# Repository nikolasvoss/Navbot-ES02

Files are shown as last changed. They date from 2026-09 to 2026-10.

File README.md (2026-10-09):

# Navbot-ES02 - Open Source Desktop Dual-Wheel Legged Robot

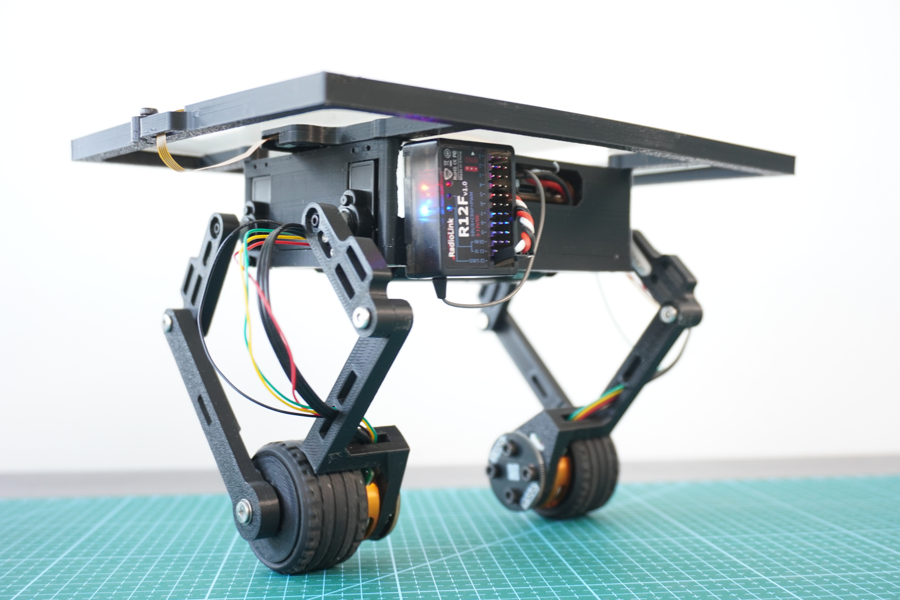
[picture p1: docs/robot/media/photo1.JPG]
robot


**Navbot-ES02** is a compact, open-source desktop robot that combines self-balancing wheels with articulated legs. It’s an experimental platform for exploring locomotion, balance, and user interaction — ideal for makers, educators, and robotics enthusiasts.

Full tutorial: [Frank Fu’s Build Guide](https://frankfu.blog/embodied-ai-robot/diy-desktop-dual-wheel-legged-roboy/)

---

##  Key Features

-  **Self-balancing** using MPU6050 and PID control
-  **Legged motion** using 270° digital servos
-  **Touchscreen interface** for motion control to achieve  ball-balancing
-  **Radiolink T12D RC System** for real-time operation switching via PWM/SBUS.
-  **Modular Arduino-based firmware** for easy customization

---

## Hardware Overview

| Component | Description |
|---|---|
| **MCU** | ESP32-S3 DevKit |
| **Motors** |  2208 90KV 3mm Shaft Gimbal Brushless Motors |
| **IMU** |  ICM42688 a 3-axis gyroscope and a 3-axis accelerometer |
| **Servos** | Pro-Tronik PTK 7452 MG-D 2.8kg/0.11s 12.3g Micro Digital Servo |
| **HMI** | 2.8" resistive/capacitive touchscreen |
| **Battery** | 2Pcs 18650 Battery Charger Pack |
| **Controller** | Radiolink T12D 12CH 2.4G RC Transmitter R12F Receiver |

---

## 📦 Software Structure

```
Navbot-ES02/
├── OllieFOCdrive/     # Motor & balance control
├── TouchUI/           # Touchscreen-based user interface
├── WiFiControl/       # Optional WebSocket/HTML control panel
├── partitions.csv     # Flash partition layout
└── lib/               # Required Arduino libraries
```

---

The current firmware supports the two-wheel balancing robot only. Legacy four-wheel gait control and master/slave communication have been removed. UART1 remains available for the touchscreen, and UART2 handles SBUS.

## Project documentation

The canonical hardware and software documentation follows the two target trees:

- [Robot and ESP32 hardware](docs/robot/hardware/system-overview.md), [robot software/control](docs/robot/software/control/control-flow.md), and the [BLE communication protocol](docs/robot/software/interfaces/NavBot-ES02-BLE-communication-protocol-V1.2.pdf).
- [ros2_pc hardware and attached peripherals](docs/ros2_pc/hardware/README.md) and [ros2_pc software/roadmap](docs/ros2_pc/software/README.md). ros2_pc details remain pending until hardware is selected and verified.

## Getting Started

### 1. Install Requirements

- Arduino CLI with the ESP32 board package installed
- Libraries (via Library Manager or GitHub):
  - [SimpleFOC](https://github.com/simplefoc/Arduino-FOC)
  - [SimpleFOcDrivers](https://github.com/simplefoc/Arduino-FOC-drivers)
  - ArduinoJson
  - Queue (`cppQueue.h`)

The repository does not pin the ESP32 core or Arduino library versions. The build uses the versions installed in your Arduino CLI environment.
Used library versions are recorded per build in firmware-build-environment.json.
    
### 2. Build and flash the firmware

```bash
git clone https://github.com/fuwei007/Navbot-ES02.git
cd Navbot-ES02
python3 scripts/build_firmware.py
```

The command builds the NavBot sketch into `build/flash`. Run `python3 scripts/build_firmware.py --help` to choose another sketch, board, output directory, or build properties. To flash a compiled build, use the configured `navbot_flash` MCP tool `flash_firmware` with the absolute build directory from the active worktree. Check the serial MCP `list_ports` before reporting that the board is disconnected, close the serial MCP connection before flashing, and keep balance disabled with motor outputs safe. See the [canonical USB/serial documentation](docs/robot/software/development/usb-serial-flashing.md) for board settings and verified connection details.

### Safe sensor diagnostics

The full, current procedure is in the [sensor diagnostic guide](docs/robot/software/diagnostics/sensor-diagnostic-mode.md), including safe motor outputs, build and flash steps, SerialPlot settings, the 17-column channel map, and reset troubleshooting. The source currently sets `SENSOR_DIAGNOSTIC_MODE=0`, which builds normal motor-control firmware. Set it to `1` and rebuild for sensor diagnostics. Diagnostic mode skips motor and servo initialization and holds the wheel-driver enable pins low. Support the robot mechanically because the legs are not driven. The diagnostic stream currently uses 576000 baud through the CH340 UART at the user's direction. The hardware UART rate at 576000 has not yet been measured, and this setting is not hardware-accepted.

With the normal image, SerialPlot can log one raw SBUS receiver channel while the robot runs. Use `K60` for CH1 through `K75` for CH16. Each row contains firmware uptime in seconds and the selected channel value. Send `K0` to stop logging. The [sensor diagnostic guide](docs/robot/software/diagnostics/sensor-diagnostic-mode.md) has the SerialPlot setup steps.

### Capture a balance shutdown

With `SENSOR_DIAGNOSTIC_MODE` set to `0`, upload the rebuilt sketch and support the robot so it cannot fall. Close every other serial monitor, then run:

```bash
python3 scripts/capture_balance_trace.py --seconds 20 --output balance-trace.log
```

The script waits for startup, sends `K55`, and records a nominal 142.9 Hz `TRACE` stream, one row for every seventh executed control gate (nominally 1 kHz). Switch RC channel 5 from off to on **once** during the capture. The columns are `time_ms,ch5_mode,ch6_mode,voltage_min_raw_v,voltage_filtered_v,roll_deg,pitch_deg,servo1_cmd_deg,servo2_cmd_deg,servo3_cmd_deg,servo4_cmd_deg,servo1_range_deg,servo2_range_deg,servo3_range_deg,servo4_range_deg,motor1_target,motor2_target,sequence,logger_dropped,uart_write_failures`. Each `range` is the highest minus lowest integer servo command since the preceding row, nominally 7 ms. The minimum voltage uses all battery ADC samples since the previous row; it is still a board ADC estimate, not a measurement of the ESP32's 3.3 V rail. The servo values are commanded angles, not measured shaft positions. The saved log also includes any reboot or brownout text that reaches the serial port. The script sends `K0` at the end to stop tracing. If the robot loses power, retain the log even if the script reports a port error.

After uploading firmware built from the current source, add `--trace-mode 56` and choose a new output file to capture the compact `CTRL` stream instead. It records `time_ms,ch5_mode,voltage_min_raw_v,voltage_filtered_v,roll_deg,gyro_z_rad_s,body_turn_command,angle_error_deg,angle_output,yaw_error,yaw_output,motor1_target,motor2_target,max_servo_range_deg,sequence,logger_dropped,uart_write_failures`. The angle and yaw outputs are the two terms combined into the wheel targets; an inactive balance mode reports zero for their error/output columns. Selected trace modes suppress repeated low-voltage and BLE debug text to keep it out of CSV rows. `body_turn_command` and `yaw_error` use the firmware's numerical scale; do not assume they are physical rad/s without checking the RC mapping. Existing firmware images that only implement `K55` must be reflashed for this mode.

For controller decomposition, `--trace-mode 57` records `BAL` rows: `time_ms,ch5_mode,voltage_min_raw_v,roll_deg,angle_error_deg,angle_out_p,angle_out_i,angle_out_d,body_x,motor1_target,motor2_target,max_servo_range_deg,sequence,logger_dropped,uart_write_failures`. Its shorter lines use the same asynchronous sender and 576000 baud stream. Give each run a unique output filename.

For forward/reverse motion and stopping behavior, `--trace-mode 58` records `DRIVE` rows: `time_ms,ch5_mode,voltage_min_raw_v,voltage_filtered_v,ch3_target,effective_speed_target,motor1_velocity_f,motor2_velocity_f,tick_dt_s,speed_error,speed_out_p,speed_out_i,speed_out_d,speed_output,speed_body_x_raw,body_x,body_pitching_f,roll_ok,angle_output,angle_out_p,angle_out_i,angle_out_d,wheel_speed_feedback,motor1_target,motor2_target,top_ball_x,touch_x,body_pitching,max_servo_range_deg,sequence,logger_dropped,uart_write_failures`. Use this only after confirming the trace output with CH5 off; each run should have a new filename. The logger samples nominally at 142.9 Hz without changing controller gains or the control-gate cadence. Nyquist is about 71.4 Hz; signals above that can alias, and the configured 50 Hz IMU low-pass cutoff is based on nominal 1 kHz sampling rather than a measured runtime cadence. No active-balance hardware measurement has established control-cycle timing or UART integrity under transmission load.

The current `DIAGNOSTIC_LIVE_TUNING_DEFAULTS=1` build starts with angle P/I/D=5/200/0.11 and integral limit 0.1, speed P/I/D=0.045/0.005/0 and integral limit 50, yaw P/I/D=4/0/0, and direct wheel-speed feedback `V=0`. Live tuning starts enabled (`U1`), and these gains also apply when the physical CH5 switch passes briefly through mode 1. Keep CH9 and CH10 centered during driving. The startup speed integral is `SI0.005`, matching the live settings the user reported as free of vibration on 2026-10-01. This observation tested the complete gain set, not the speed integral in isolation. The direct wheel-speed feedback contributes only when the driver requests less speed in the current direction or commands a reversal, including after CH3 returns to neutral, and is limited to ±8 motor-target units. `V0` disables it. `V` reads the current value. The speed-loop BodyX term is limited to ±10 mm and its unsaturated value appears as `speed_body_x_raw` in the DRIVE trace. When absolute `roll_ok` exceeds 5°, further acceleration demand is reduced progressively; by 10° the speed-loop acceleration request is zero. These two angles are initial tuning values. Braking requests and the inner balance output remain available. Compare `ch3_target` with `effective_speed_target` to see the reduction. `W` reads the tilt-reduction strength (default 1), and `W0` disables this new reduction immediately for comparison; `W1` restores it. Live tuning remains enabled, but no USB connection is needed to run the robot after flashing. The wheel speed estimate uses the measured control tick. The SBUS CH3 command is multiplied by 2.0; `ch3_target` shows the scaled target. `SP0.04` changes speed P live; `SP` reads it back. `PL0.05` changes the angle integral limit live; `PL` reads it back. `PP`, `PI`, `PD`, and `YP` read the other relevant gains. `U0` restores this build's tuned startup defaults at the next active control step; `U1` keeps live tuning. Live changes are not stored in flash and reset to these startup values after reboot. The CH3 scaling is fixed in this build and cannot be tuned through serial commands.

To log commands and telemetry through one serial connection, run `python3 scripts/capture_balance_trace.py --trace-mode 56 --interactive --seconds 40 --output control-live-yaw10.log`. The script logs every trace row and each sent command (`# CMD ...`), while showing only every tenth trace row in the terminal. With CH5=0, type `PP` and `YP` to verify the startup gains before entering CH5=2. The interactive input accepts only gain, `U0`/`U1`, and trace-selection commands; it cannot send calibration or motor-drive commands.

For a repeatable agent-facing run summary, pass one or more saved logs to `scripts/summarize_balance_trace.py`. It reports valid and malformed rows, capture span, CH5 mode counts/transitions, and a small set of min/max/mean values without making causal claims:

```bash
python3 scripts/summarize_balance_trace.py balance-trace.log
python3 scripts/summarize_balance_trace.py run-1.log run-2.log --output balance-summary.md
```

For repeated K58 drive/stop trials, one command captures a new log at 576000 baud and writes a short `*.md` report after capture. It refuses to overwrite an existing log or report:

```bash
python3 scripts/run_drive_trial.py --interactive --output drive-test-01.log --seconds 40
```

The report checks trace quality, CH5 activation, CH3 movement, start tilt, and the largest opposite wheel-speed reading in the first second after a CH3 release. If there is no usable stop event, the command returns status 2 and keeps both files. It does not switch the robot. With `--interactive`, type a gain command such as `SP0.04`, then `SP` to read it back, before enabling CH5. The capture logs accepted commands as `# CMD ...` and includes firmware replies. Use a new filename for each gain setting and state the observed movement with the report path. Opening a new serial session may restart the board, so set and read back live gains again in each run.

Compare saved trials without opening Serial or recompiling firmware:

```bash
python3 scripts/analyze_drive_trace.py drive-test-01.log drive-test-02.log --require-stop --output drive-comparison.md
```

`--format json` provides the same measurements for other scripts. A trial with neutral CH3 or a strongly tilted start is flagged as unsuitable for a stop comparison; it is not interpreted as a controller improvement or regression.

### 3. Connect the model remote control
ES02 has 3 lines, namely GND, 5V, and sbus.

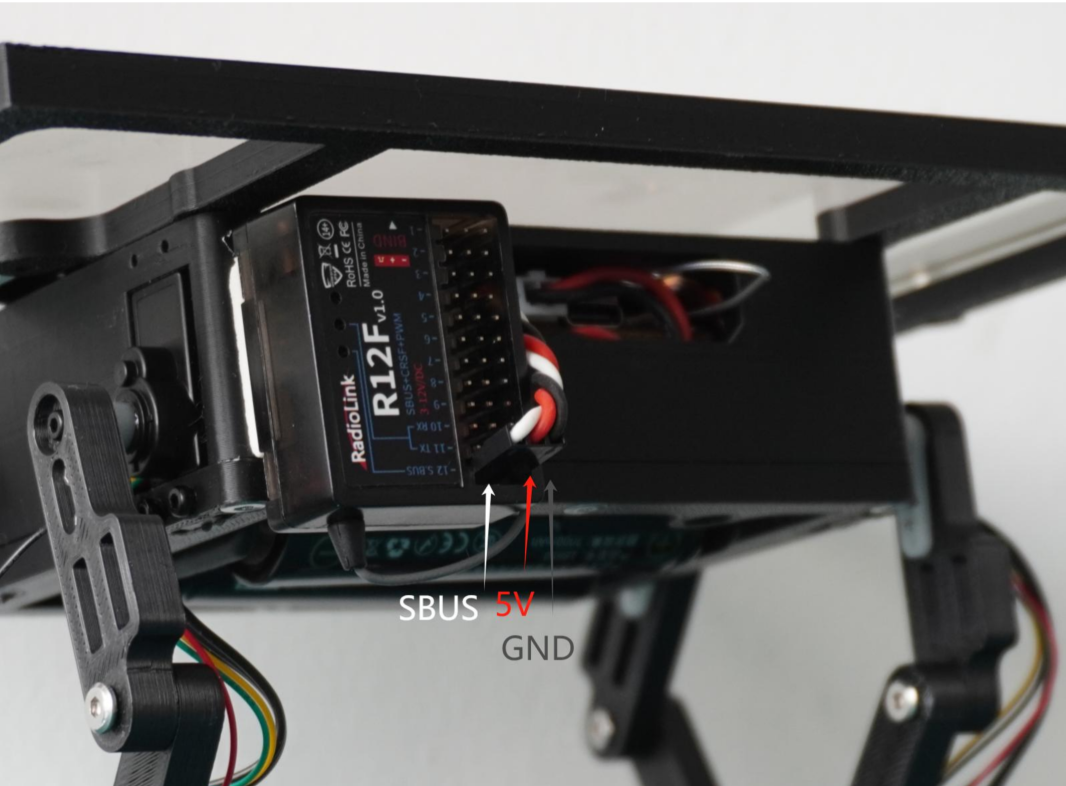
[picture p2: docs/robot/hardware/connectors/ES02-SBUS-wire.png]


The remote control receiver may have multiple interfaces. It is necessary to confirm the sbus
output port by yourself. The following picture shows the wiring ports of the RadioLink receiver.

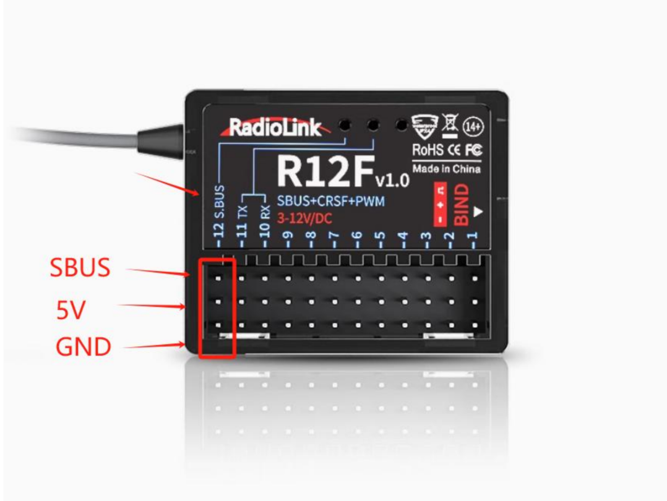
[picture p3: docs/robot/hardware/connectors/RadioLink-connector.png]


The channels of the joystick are generally defaulted to ch1-4. Besides, six auxiliary channels
are needed to switch on some functions. Each remote control is different, and they should be set
according to personal habits. The corresponding functions of ch6-10 can be referred to as follows:

- CH5 : 3-section switch, 0:stop, 1:start, 2:start and touch tablet enable. 
- CH6 : 2-section switch, 0:posture mode, 1:mark mode. 
- CH7 : 2-section switch, manual or auto roll, 0:manual , 1:auto . 
- CH8 : 3-section switch, 0:default, 1:pitching adjust, 2:ball poise. 
- CH9 : The x-coordinate of the small ball . 
- CH10:The y-coordinate of the small ball.

---

## Tourial Videos

- DIY ES02 Desktop dual-wheel legged bot Preview:
  
  Video 2 (https://www.youtube.com/watch?v=u7Jmyq_AXwc)

- Open Source ESP32 DIY Robot ES02: Learn Coding & Robotics | Educational Dual-Wheel Legged Bot:
  Video 1 (https://www.youtube.com/watch?v=hujr_VRSyrw)

---

## Discord link
| Link: [https://discord.gg/syywQ2CKN3](https://discord.gg/syywQ2CKN3)        |
| :------------: |
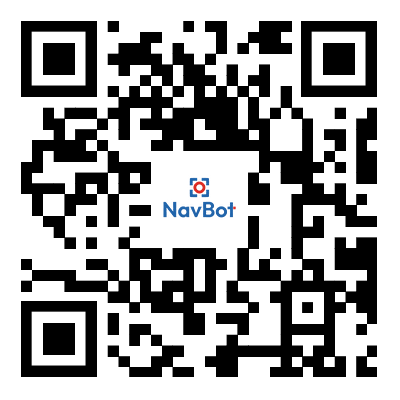
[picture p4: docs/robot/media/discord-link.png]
|  |

---

## Acknowledgments

- [SimpleFOC Community](https://simplefoc.com/)
- [Frank Fu’s Robotics Blog](https://frankfu.blog)
- [LVGL GUI Library](https://lvgl.io/)
- Arduino & ESP32 Open Source Communities

---

> Feel free to fork, contribute, or build your own version!  
> PRs and feedback are always welcome.

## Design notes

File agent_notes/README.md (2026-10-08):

# Agent-only notes

This directory holds agent working context, open investigations, and evidence from the assembled robot. It is not the canonical hardware or software documentation. Put stable, complete documentation under `docs/robot/` or `docs/ros2_pc/`, and keep dated observations with their evidence here.

- [Robot agent notes](robot/README.md)
- [ros2_pc HMMD sensor evidence and references](ros2_pc/sensors/hmmd/README.md)

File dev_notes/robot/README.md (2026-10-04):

# Robot work notes

- Confirm the sender's actual SBUS channel assignments in its monitor. The [RC channel map](../../docs/robot/software/control/rc-channel-map.md) documents the firmware mapping, not the HOTRC switch setup.
- Build with `python3 scripts/build_firmware.py`. For uploads, follow `AGENTS.md` and use the configured `navbot_flash` tool with the active build directory.
- Check the [hardware overview](../../docs/robot/hardware/system-overview.md) before changing wiring. It distinguishes the PCB design from observations on the assembled robot.
- Read the [sensor diagnostic guide](../../docs/robot/software/diagnostics/sensor-diagnostic-mode.md) before collecting sensor-only serial data.

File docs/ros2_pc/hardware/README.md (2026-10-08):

# ros2_pc-Hardware

This directory documents the ros2_pc, its carrier board, power supply, connectors, and attached hardware.

The project has not yet recorded confirmed ros2_pc or carrier-board details here. Do not infer pin assignments, power limits, or peripheral connections from the roadmap. Add each fact with its board revision and evidence when the hardware is selected or inspected.

The [ros2_pc carrier-board pinout](ros2-pc-carrier-board.md) is a reference. It does not confirm that the project has selected or verified that carrier board.

The planned HMMD radar and Roborock LiDAR work is listed in the [ros2_pc software roadmap](../software/roadmap.md). Record their electrical and mechanical details here only after the exact modules are identified.

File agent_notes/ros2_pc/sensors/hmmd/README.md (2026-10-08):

# HMMD-Sensor für Agenten

## Auftrag und aktueller Stand

Der erste [Roadmap-Meilenstein](../../../../docs/ros2_pc/software/roadmap.md) zeigt die HMMD-Range-Doppler-Map stationär in ROS 2 auf dem ros2_pc. ROS 2 ist laut Nutzer bereits auf dem ros2_pc installiert. Die genaue Distribution ist noch nicht erfasst. Sensoranschluss und Live-Daten sind noch nicht geprüft.

## Dokumente finden

- [Lokale Herstellerunterlagen](vendor/README.md) enthält Wiki, Radome-Leitfaden, Beispielpaket und Prüfsummen.
- [HMMD ROS 2 developer guide](../../../../docs/ros2_pc/software/hmmd-ros2.md) ist die zentrale Anleitung zum Bauen und Verwenden der Software.
- [Protokollreferenz](protocol.md) enthält Herstellerangaben und ihre Grenzen.
- [Beobachtungen und offene Punkte](observations.md) enthält den belegten Stand des Aufbaus.
- [Hardwareübersicht](../../../../docs/robot/hardware/system-overview.md) beschreibt die bestehende Navbot-Elektronik. Der stationäre Radaraufbau ist davon getrennt.
- [USB- und Serial-Regeln](../../../../docs/robot/software/development/usb-serial-flashing.md) gelten vor seriellem Zugriff.

## Hinweise für ausführende Agenten

Lies zuerst diesen Einstieg, danach nur die für den Auftrag benötigte Referenz. Unterscheide Herstellerangaben, Nutzerangaben, Vorschläge und gemessene Beobachtungen. Die Quelle des jeweiligen Eintrags entscheidet über seine Aussagekraft.

Verwende für direkte serielle Zugriffe den konfigurierten Serial-MCP. Ermittle den Port mit `list_ports`. Setze nach `open` RTS und DTR niedrig, sofern der Auftrag nichts anderes erfordert. Sende Befehle nur für einen entsprechenden Auftrag. Auf dem ros2_pc muss der Sensor über den verwendeten MCP erreichbar sein.

Prüfe vor Versorgung oder Verkabelung die tatsächliche Modulvariante, Pinbelegung, Spannung und Signalpegel. Übertrage die Pinbelegung eines Raspberry-Pi-Beispiels nicht ungeprüft auf das ros2_pc-Trägerboard.

Notiere neue Hardwarebefunde in `observations.md` mit Datum, Beobachtung, Evidenz und praktischer Konsequenz. Aktualisiere `protocol.md` nur bei belegten Protokollbefunden. Bewahre Rohmitschnitte und Messwerte als Evidenz auf. Dokumentiere Annahmen ausdrücklich.

Nutze Bin-Indizes für die erste Heatmap. Gib keine Meter- oder Geschwindigkeitsachsen ohne nachgewiesene Skalierung an. Die Map liefert keine Links-rechts-Ortung.

Ändere für den stationären Test weder ESP32-Firmware noch Balance-, Motor- oder Fahrsteuerung. LiDAR, SLAM und Navigation gehören zu späteren Aufgaben.

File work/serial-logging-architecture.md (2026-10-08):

# Serial logging merge architecture

## Target behavior retained

The target branch already owns the CH340 `Serial` stream at 576000 baud, a bounded `SerialLogger`, and capture scripts for diagnostic and TRACE/CTRL/BAL/DRIVE rows. Diagnostic mode samples every 10 ms and emits 17 numeric fields. Selected TRACE/CTRL/BAL/DRIVE rows are produced at the existing every-seventh-control-gate boundary. Those formats and rates remain unchanged.

Normal control invokes `print_data()` from the main loop. Selectors 1–45 previously formatted and wrote their values inline. They now copy those already available values into a fixed selected-debug record at the same call boundary. Selector 8 keeps its existing 50 ms throttle. Selectors 55–58 continue through the target's typed row builders and retain the existing CSV suffix fields consumed by capture and summary tools.

## Single queue and sender

The target `SerialLogger` is the only asynchronous logger. Its fixed record union holds either an existing target row or a selected-debug payload. One statically allocated `xQueueCreateStatic()` queue has 32 records; its control block and byte storage are marked `DRAM_ATTR`. On the ESP32, a `SerialLogRecord` is 168 bytes and the queue reserves 5,376 bytes of internal RAM.

The producer snapshots fields into the fixed record and calls `xQueueSend(..., 0)`. It does not format text, allocate memory, write to Serial, or wait for the queue. The logger sender receives a record before formatting it in a 384-byte stack buffer and writing it to Serial, so a blocked UART holds neither the producer nor a queue slot.

On first queue overflow, sender startup failure, or sender write failure, a small sticky status records the reason. Subsequent submissions are rejected and a saturating 8-bit rejected count is retained. The stream has no completion marker or successful-completion state. Queue and sender status do not change motor enables, balance calculations, or fall/safety decisions.

Selected debug output is the only new record kind; it uses the existing SerialLogger sender. The mode gate suppresses other existing BLE/robot debug prints while a selected log mode is active, avoiding another concurrent debug writer. Existing Commander and setup output are not serialized with these records and may still interleave as before.

## Verification

`scripts/test_serial_logger.py` compiles the actual formatter and sender against host FreeRTOS/UART stubs. It blocks the sender inside the UART write, fills the 32-slot queue, times the rejecting producer call, releases the writer, and checks FIFO output, reuse, overflow status, and the target CSV column counts. Normal and diagnostic firmware builds verify the target FreeRTOS integration. Hardware timing and CH340 receive behavior are not measured by these checks.

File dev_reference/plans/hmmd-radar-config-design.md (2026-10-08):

# HMMD radar configuration design

## Caller usage

The radar page shows a small settings area next to or directly below the heatmap. On first connection it reads the confirmed values. Each row has one integer draft and an Apply button:

- **Maximum distance gate**, 0–15 gates. Help: “Limits the farthest distance gate used for detections.”
- **Target disappearance delay**, 0–65535 seconds. Help: “How long a target remains reported after it disappears.”

The page keeps draft values separate from device-confirmed values. A displayed value changes only after the corresponding setting is read back. Save acknowledgment is shown as a separate fact and does not imply persistence across power loss. Bridge timeout/disconnect or device timeout leaves the last confirmed value visible but stale until a fresh read.

```js
const settings = new RadarSettings(client);
await settings.read(); // both confirmed device values
await settings.set("maximumDistanceGate", draft);
await settings.set("targetDisappearanceDelaySeconds", draft);
```

The UI and ROS boundary reject invalid integers and ranges. Only one setting is written per operation, so a stale draft cannot rewrite the other setting.

## Ownership and module map

- `hmmd_interfaces` defines two typed ROS services: one coherent read of both settings and one write of exactly one selected setting.
- `hmmd_radar.protocol` privately encodes verified firmware v1.6.1 commands and decodes command replies; the existing map parser remains specialized for map frames.
- `SerialSession` remains the only UART reader and writer. It exclusively coordinates command replies and map frames during a bounded transaction, retaining complete interleaved maps in a bounded buffer for publication when the service returns.
- `HmmdSensorNode` validates service inputs, maps session outcomes into typed responses, and publishes any map frames collected by the session. Keep the current single-threaded executor; do not add a lock or second reader.
- The production endpoint manifest declares only the two new services. `RosbridgeClient.callService` remains the browser transport.
- `web/radar_settings.mjs` hides ROS selector/outcome details behind `read()` and `set(setting, value)`. `app.mjs`, `index.html`, and `style.css` render two controls near the radar image with draft, confirmed, pending, stale, and error states.
- Extend the existing protocol/session/ROS and browser fixture tests for observable contracts. Update `docs/ros2_pc/software/hmmd-ros2.md` and `agent_notes/ros2_pc/sensors/hmmd/protocol.md` with the service behavior and actual hardware evidence.

## Service contract

`GetRadarConfig.srv` returns both settings only when both device reads are valid, plus explicit outcome/stage and concise detail. `SetRadarSetting.srv` accepts a closed setting selector and one integer value. The driver performs write → positive ACK → same-setting readback → exact match → save → positive save ACK. It returns separate write/save ACK flags, observed value when available, and named outcome/stage. A response is successful only when the readback matches and save is acknowledged. It must not claim power-cycle persistence.

Reject unknown selectors, booleans, non-integers, and out-of-range requests before serial I/O. A write timeout is uncertain; never retry it automatically, and require a fresh read before another write. Keep per-stage and total deadlines finite, with the service/manifest timeout longer than the session transaction. Drop late command replies rather than associating them with a subsequent operation.

## UART/map transaction

The current single-threaded `rclpy.spin()` serializes polling and service callbacks. During the synchronous service callback, `SerialSession` itself drains bounded chunks and classifies both map and command frames; it routes only the matching reply to the active step and retains complete map frames in a bounded buffer for the next publish. This briefly pauses ROS map publication but does not silently discard interleaved map frames. Keep one outstanding device command. Do not retry after I/O loss because the device may have applied the write before disconnection.

The hardware evidence covers firmware `v1.6.1`, maximum gate `12`, and disappearance delay `30 s`: each unchanged value was written, positively acknowledged, read back, and followed by a save acknowledgment. This does not establish power-cycle persistence or authorize changing either value in this task.

## Synthesis decision

Use candidate 1's coherent snapshot read and per-setting write services. Graft candidate 3's domain-oriented browser wrapper so page code does not manipulate ROS selectors or numeric result codes. The read/set transaction stays in one `SerialSession`; candidate 2's paired-value write is rejected because a one-row edit could rewrite a stale value. Candidate 3's generic operation/setting service is rejected because it permits meaningless field combinations and makes stage reporting less precise. The cross-judge found no red-flag blocker and favored this shape for correctness and scope.

The Gemini CLI review did not run successfully: its adapter rejected the supplied task name before reviewing any design. No Gemini findings are attributed to this decision.

## Tradeoffs and open risks

- Keep synchronous bounded transactions and accept a short map publication pause; revisit the ownership model only if measured device latency exceeds the budget.
- Keep explicit browser and ROS validation at their external boundaries and validate all protocol replies before reporting them.
- A timeout after a write is unknown outcome, not proof the setting stayed unchanged. Refresh before another write.
- A save ACK confirms command acceptance only; power-cycle persistence remains untested.
- Preserve maps received during an exchange in a bounded queue; no unbounded buffering.
- Verify the service timeout hierarchy and late-reply drain behavior against the actual serial-session implementation and synthetic streams before enabling the browser control.

## Verification contract

Exercise only no-change hardware writes at gate `12` and delay `30 s`; no deployment or value change. Software checks cover exact boundaries and invalid values, command/reply correlation, ACK/readback/save outcomes and timeouts, interleaved map retention, bounded buffering, no automatic retry, ROS response mapping, manifest-derived endpoints, and browser confirmed-only/reconnect behavior. Existing map/status operation must remain available.

## Implementation reconciliation

The v1.6.1 read replies contain the command ID and uint32 value but do not echo the parameter ID. The serialized session therefore associates a reply only with its one outstanding read step; it drains late command replies between steps and quarantines a timed-out command ID before reusing it. It never retries a setting write. The measured read sequence enters config mode, reads parameter IDs 1 and 4, and sends the acknowledged `0x00FE` exit command. A snapshot succeeds only when both reads and that exit ACK succeed. A setting write stays blocked after an uncertain write or readback mismatch until a successful fresh snapshot.

The mixed stream parser retains the existing map decoder for complete map frames and adds command-frame classification in the same bounded UART stream. Complete maps seen during a service transaction wait in a bounded 64-frame queue for the next poll; queue overflow is counted in HMMD diagnostics. Command stages have finite 350 ms response deadlines and a short bounded late-reply drain, below the 5 s browser service timeout. No second UART reader or executor was introduced.

If later measurements show the finite synchronous transaction exceeds the service budget, stop and return to design/scope review before changing ownership or concurrency.

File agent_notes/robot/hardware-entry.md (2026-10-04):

# Robot hardware entry for agents

Read the [canonical system overview](../../docs/robot/hardware/system-overview.md) first. Open only the needed section of the [electronics reference](../../docs/robot/hardware/electronics/reference.md), then search the [netlist](../../docs/robot/hardware/electronics/netlist.md) for exact designators or nets.

The PCB netlist describes intended connections. Firmware describes configured behavior. The BOM lists proposed parts. Notes under `agent_notes/robot/hardware-findings/` record observations on the assembled robot. Check the physical board when orientation, assembly, or actual wiring remains uncertain.

Before a flash, recheck the board and serial device. See the [USB and serial reminder](usb-serial.md) and the complete [USB and flashing guide](../../docs/robot/software/development/usb-serial-flashing.md).

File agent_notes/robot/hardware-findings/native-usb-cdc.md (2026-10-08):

# Native USB CDC constraint, 2026-10-07

## Observation

Native ESP32-S3 USB CDC is unavailable through the existing USB-C connector without hardware changes. This conclusion combines PCB routing, firmware pin use, and existing device observations. No new physical continuity measurement or wiring trial was performed.

## Evidence

- [PCB netlist](../../../docs/robot/hardware/electronics/netlist.md): `USB1` D+/D− connect to CH340X `U3` UD+/UD−. ESP32 module `U4` GPIO19/20 connect to `RX1`/`TX1` instead.
- [Touch firmware](../../../src/ES-02/OllieFOCdrive/touchscreen.h) uses GPIO20 as UART1 RX and GPIO19 as UART1 TX.
- [Espressif hardware requirements](https://docs.espressif.com/projects/esp-idf/en/stable/esp32s3/api-guides/usb-serial-jtag-console.html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) assign native USB D− to GPIO19 and D+ to GPIO20.
- [Existing board observations](../../../docs/robot/software/development/usb-serial-flashing.md): USB-C enumerated as CH340; enabling USB CDC did not expose a native CDC port and routed sketch output away from the observed UART connection.

## Practical consequence

Use the existing CH340 UART path for logging trials. Native USB requires a separate connection to GPIO19/20 and resolution of the touch-UART conflict, with layout and physical pinout verification before wiring. A firmware option cannot change the USB-C data routing. Neither transport removes the need to keep logging transmission from blocking active balance control.

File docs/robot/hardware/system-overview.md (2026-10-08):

# Roboter mit ESP32: Elektronik-Hardware im Überblick

**Zweck:** Diese Seite in etwa einer Minute lesen. Für Pinbelegung, Strompfade und Quellen nur den benötigten Abschnitt in [hardware reference](electronics/reference.md) öffnen. Für einzelne Bauteile und unbenannte Netze gibt es zusätzlich die durchsuchbare [Bauteil-Netzliste](electronics/netlist.md). Die Angaben beziehen sich auf das eingecheckte EasyEDA-Projekt und die aktuelle Firmware, nicht auf eine Messung jeder Leiterbahn der aufgebauten Platine.

## System auf einen Blick

```text
2 × 18650 in Serie ── Schutz / Schalter ── VIN (2S)
                                         ├─ 2 × MP6536 → 2 × dreiphasiger 2208-Radmotor
                                         ├─ RT8289 → +5 V → XC6210 → +3,3 V
                                         └─ wählbare Servoversorgung (+5 V oder VIN)

ESP32-S3-WROOM-1 (MAIN)
  ├─ 2 getrennte I²C-Busse → je 1 AS5600-Platine (CODER), Radwinkel für SimpleFOC
  ├─ SPI → ICM-42688P, Beschleunigung und Drehrate für Lage/Balanceregelung
  ├─ 6 PWM + 2 Enable → 2 Motor-Endstufen; 4 PWM → Beinservos
  ├─ UART2 → invertierter SBUS-Empfänger; UART1 → Touch-TTL
  ├─ UART0 → CH340X → USB-C für Flash und Serial
  ├─ GPIO17/ADC → 2S-Akkuspannung über 10-kΩ/1-kΩ-Teiler
  └─ BLE → Steuerung ohne zusätzlichen Funkchip
```

Das EasyEDA-Projekt enthält **MAIN** (Steuerung, Versorgung, Motortreiber, Anschlüsse) und **CODER** (AS5600-Encoderplatine; zwei Exemplare laut BOM). Die Mechanik hat zwei bürstenlose Radmotoren und vier Beinservos. Die resistive Touchfläche wird laut BOM über eine separate TTL-Treiberplatine angebunden. RC-Steuerung erfolgt über einen externen Empfänger und dessen SBUS-Ausgang.

## Schnelle Orientierung

| Aufgabe | Relevante Hardware | Direkt weiterlesen |
| --- | --- | --- |
| Radmotor dreht nicht / FOC | MP6536 `U6/U7`, drei Motorphasen je Rad, AS5600 `H5/H6` | [Motoren und Encoder](electronics/reference.md#motoren-und-encoder) |
| Lage, Balance oder Fahrverhalten prüfen | ICM-42688P `U5` an SPI, Akku-ADC `GPIO17` | [Regelungsablauf](../software/control/control-flow.md#noch-nicht-geklärt), [Sensoren](electronics/reference.md#sensoren-und-signale) |
| Servo, Versorgungseinbruch | Vier Servoausgänge `H9/H10`, Versorgungsauswahl `H11`, `VIN` aus 2S-Akku | [Stromversorgung](electronics/reference.md#stromversorgung) und [Anschlüsse](electronics/reference.md#anschlüsse) |
| Fernsteuerung | `H4`: GND, +5 V, SBUS; Inverter `Q1`; ESP32 `GPIO1` | [Anschlüsse](electronics/reference.md#anschlüsse) |
| Touch oder UART | `H2`/`CN4`: UART1; `H3`: UART2; `H1`: UART0 | [Serielle Schnittstellen](electronics/reference.md#serielle-schnittstellen) |
| Einzelner Widerstand, IC-Pin oder unbenanntes Netz | Alle elektrisch verbundenen Pads beider PCBs | [Bauteil-Netzliste](electronics/netlist.md) |
| Flash / USB-Diagnose | USB-C → CH340X → UART0; nicht als natives USB-CDC voraussetzen | [USB/serial guide](../software/development/usb-serial-flashing.md) |

## Wichtige Feststellungen und Konsequenzen

- **Natives USB CDC erfordert eine Hardwareänderung:** Im PCB-Netzplan führt USB-C zu CH340X, nicht zu den nativen USB-Pins des ESP32-S3. GPIO19/20 sind für Touch-UART belegt. Natives USB CDC ist daher über den vorhandenen USB-C-Anschluss ohne Hardwareänderung nicht möglich. Eine Firmwareoption allein genügt nicht. Siehe [serielle Schnittstellen](electronics/reference.md#serielle-schnittstellen).

- **Kein externer RAM:** Laut Nutzerbestätigung vom 28.09.2026 ist ESP32-S3-WROOM-1 bestückt, ohne externen RAM; die Pinbelegung ist korrekt. Die N8R8-Angabe der Netzliste weicht von dieser Hardwareangabe ab. Nur internen SRAM für Logging einplanen; siehe [Hardware constraints for logging](wireless-logging-constraints.md).

- **Servo-Stromschiene:** `H11` verbindet den gemeinsamen Versorgungs-Pin der Servostecker wahlweise mit `+5V` oder `VIN`. Vor Anschluss und Belastung die tatsächlich gesteckte Brücke und die Spannungsverträglichkeit der Servos prüfen. Die Servos hängen nicht am 3,3-V-Regler. Quelle: MAIN-PCB-Netzliste (`H9`, `H10`, `H11`).
- **Akkumessung:** Die Firmware errechnet aus dem GPIO17-ADC einen Akkuwert. Es ist **keine Messung der 3,3-V-Schiene**. Die dokumentierten Messwerte fallen unter Balance-Last stark; Akku, Kontakt, Regler und ADC-Verhalten sind damit noch nicht getrennt beurteilt. Quelle: MAIN-Netzliste `R1/R2`, `ReadVoltage()` und [sensor diagnostic guide](../software/diagnostics/sensor-diagnostic-mode.md).
- **Encoder:** Die gleichen AS5600-I²C-Adressen sind möglich, weil die zwei Radencoder an getrennten ESP32-I²C-Controllern hängen: `GPIO4/5` und `GPIO41/42`. Quelle: MAIN-/CODER-Netzliste und Firmware-Initialisierung.
- **SBUS:** Der Empfänger wird über `H4` mit 5 V versorgt; das Signal läuft über den Transistor `Q1` invertiert zu `GPIO1`/UART2. Den Empfänger-Ausgang und die Pin-Reihenfolge vor dem Stecken prüfen. Quelle: MAIN-Netzliste und [SBUS-Anschlussblatt](connectors/ES02-SBUS-connect.pdf).
- **UART1-Zuordnung:** Die PCB-Netze `RX1`/`TX1` liegen laut ESP32-Symbol an GPIO19/20, die Firmware verwendet für UART1 jedoch RX=GPIO20 und TX=GPIO19. Das ist eine echte Abweichung zwischen Netzbenennung und Softwarebelegung; die Kabelbelegung nicht allein aus den Namen ableiten. Quelle: `U4` in der [Bauteil-Netzliste](electronics/netlist.md) und `touchscreen.h`.
- **5-V-Regler:** `U1`-Pin 5 (`EN`) erscheint im PCB-Export als unverbunden. Daraus allein lässt sich sein Betriebsverhalten nicht bestimmen; bei 5-V-Problemen diesen Pin und das Datenblatt prüfen. Quelle: [Bauteil-Netzliste](electronics/netlist.md).
- **Datenlage:** README, BOM und Schaltplan nennen bei einzelnen Zukaufteilen unterschiedliche Modelle: Die BOM nennt Servo `GX-S7445`, das README `Pro-Tronik PTK 7452 MG-D`. Das README erwähnt außerdem an einer Stelle `MPU6050`, während Schaltplan, BOM und Firmware `ICM-42688P` belegen. Für Pin- und Schaltungsfragen die PCB-Netzliste, für die aktuell ausgeführte Funktion die Firmware heranziehen; konkrete bestückte Kaufteile am Roboter prüfen.

## Quellen und Geltung

- **Schaltplan/Netzliste:** [`hardware/pcb/ProPrj_NavBot-ES02.epro`](../../../hardware/pcb/ProPrj_NavBot-ES02.epro), darin `project.json`, MAIN-/CODER-`.esch` und `.epcb`. Die hier genannten Steckerpins und Netznamen wurden aus `PAD_NET` der jeweiligen `.epcb` gelesen.
- **Zukaufteile:** [`BOM.xlsx`](BOM.xlsx), Tabelle `Sheet1`, Stand des Repositories.
- **Firmware-Zuordnung:** [`src/ES-02/OllieFOCdrive/OllieFOCdrive.ino`](../../../src/ES-02/OllieFOCdrive/OllieFOCdrive.ino), [`ICM42688.h`](../../../src/ES-02/OllieFOCdrive/ICM42688.h), [`touchscreen.h`](../../../src/ES-02/OllieFOCdrive/touchscreen.h), [`FUTABA_SBUS.h`](../../../src/ES-02/OllieFOCdrive/FUTABA_SBUS.h).
- **Beobachtungen am vorhandenen Board:** [USB/serial guide](../software/development/usb-serial-flashing.md) und [sensor diagnostic guide](../software/diagnostics/sensor-diagnostic-mode.md). Diese beschreiben Messungen und lokale Tests; die Netzliste beschreibt das Design.

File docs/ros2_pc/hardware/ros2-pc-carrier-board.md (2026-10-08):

# ros2_pc IO Board pinout

## Scope and status

This page is a manufacturer reference for the ros2_pc IO Board (ros2_pc carrier), the standard carrier shown in the cited Raspberry Pi documents. It does not confirm that the project has selected, bought, inspected, or installed a ros2_pc IO Board. The project’s ros2_pc hardware remains pending.

The current Raspberry Pi IO Board datasheet is document RP-008182, revision 2. Its history records the Rev 2 hardware changes dated 1 August 2025. Raspberry Pi’s design-files page lists the Rev 2 KiCad files, updated 6 October 2025. The product portal identifies the IO Board as SC1751 and SC1967. Check the revision printed on the physical board before using this reference for wiring. See the ros2_pc IO Board datasheet, [ros2_pc IO Board Rev 2 design files](https://pip.raspberrypi.com/categories/1098-design-files), and ros2_pc IO Board product page.

The GPIO alternate functions below come from the ros2_pc datasheet, Table 1. They describe the ros2_pc/RP1 mux, not a promise that every function is enabled in the project’s operating system. The board-specific connector and configuration details come from the ros2_pc IO Board datasheet. Raspberry Pi’s [camera connector pinout](https://www.raspberrypi.com/documentation/accessories/camera.html#pinout-information) and [40-pin HAT+ specification](https://datasheets.raspberrypi.com/hat/hat-plus-specification.pdf) provide connector orientation and standard-header context.

## GPIO header J8

J8 is the standard 40-pin, 2 × 20, 2.54 mm-pitch Raspberry Pi header. Physical pin numbers below follow the standard HAT+ numbering. Use the pin 1 marker on the board and the board drawing when locating pins; do not infer pin 1 from a cable view.

| Physical pins, odd column | Signal | Physical pins, even column | Signal |
| ---: | --- | ---: | --- |
| 1 | 3V3 | 2 | 5V |
| 3 | GPIO2 / I2C1 SDA | 4 | 5V |
| 5 | GPIO3 / I2C1 SCL | 6 | GND |
| 7 | GPIO4 | 8 | GPIO14 / UART0 TX |
| 9 | GND | 10 | GPIO15 / UART0 RX |
| 11 | GPIO17 | 12 | GPIO18 |
| 13 | GPIO27 | 14 | GND |
| 15 | GPIO22 | 16 | GPIO23 |
| 17 | 3V3 | 18 | GPIO24 |
| 19 | GPIO10 / SPI0 SIO0 (MOSI) | 20 | GND |
| 21 | GPIO9 / SPI0 SIO1 (MISO) | 22 | GPIO25 |
| 23 | GPIO11 / SPI0 SCLK | 24 | GPIO8 / SPI0 CE0 |
| 25 | GND | 26 | GPIO7 / SPI0 CE1 |
| 27 | GPIO0 / ID_SD | 28 | GPIO1 / ID_SC |
| 29 | GPIO5 | 30 | GND |
| 31 | GPIO6 | 32 | GPIO12 |
| 33 | GPIO13 | 34 | GND |
| 35 | GPIO19 | 36 | GPIO16 |
| 37 | GPIO26 | 38 | GPIO20 |
| 39 | GND | 40 | GPIO21 |

The bus names in the table are common mappings, not fixed assignments. The complete documented mux options follow. `a0` through `a8` are the alternate-function selector values from Table 1 of the ros2_pc datasheet. A selector omitted from a row has no named function in that table and is reserved.

| GPIO | J8 pin | Alternate functions |
| ---: | ---: | --- |
| 0 | 27 | a0 SPI0_SIO[3]; a1 DPI_PCLK; a2 UART1_TX; a3 I2C0_SDA; a5 SYS_RIO[0]; a6 PROC_RIO[0]; a7 PIO[0]; a8 SPI2_CSn[0] |
| 1 | 28 | a0 SPI0_SIO[2]; a1 DPI_DE; a2 UART1_RX; a3 I2C0_SCL; a5 SYS_RIO[1]; a6 PROC_RIO[1]; a7 PIO[1]; a8 SPI2_SIO[1] |
| 2 | 3 | a0 SPI0_CSn[3]; a1 DPI_VSYNC; a2 UART1_CTS; a3 I2C1_SDA; a4 UART0_IR_RX; a5 SYS_RIO[2]; a6 PROC_RIO[2]; a7 PIO[2]; a8 SPI2_SIO[0] |
| 3 | 5 | a0 SPI0_CSn[2]; a1 DPI_HSYNC; a2 UART1_RTS; a3 I2C1_SCL; a4 UART0_IR_TX; a5 SYS_RIO[3]; a6 PROC_RIO[3]; a7 PIO[3]; a8 SPI2_SCLK |
| 4 | 7 | a0 GPCLK[0]; a1 DPI_D[0]; a2 UART2_TX; a3 I2C2_SDA; a4 UART0_RI; a5 SYS_RIO[4]; a6 PROC_RIO[4]; a7 PIO[4]; a8 SPI3_CSn[0] |
| 5 | 29 | a0 GPCLK[1]; a1 DPI_D[1]; a2 UART2_RX; a3 I2C2_SCL; a4 UART0_DTR; a5 SYS_RIO[5]; a6 PROC_RIO[5]; a7 PIO[5]; a8 SPI3_SIO[1] |
| 6 | 31 | a0 GPCLK[2]; a1 DPI_D[2]; a2 UART2_CTS; a3 I2C3_SDA; a4 UART0_DCD; a5 SYS_RIO[6]; a6 PROC_RIO[6]; a7 PIO[6]; a8 SPI3_SIO[0] |
| 7 | 26 | a0 SPI0_CSn[1]; a1 DPI_D[3]; a2 UART2_RTS; a3 I2C3_SCL; a4 UART0_DSR; a5 SYS_RIO[7]; a6 PROC_RIO[7]; a7 PIO[7]; a8 SPI3_SCLK |
| 8 | 24 | a0 SPI0_CSn[0]; a1 DPI_D[4]; a2 UART3_TX; a3 I2C0_SDA; a5 SYS_RIO[8]; a6 PROC_RIO[8]; a7 PIO[8]; a8 SPI4_CSn[0] |
| 9 | 21 | a0 SPI0_SIO[1]; a1 DPI_D[5]; a2 UART3_RX; a3 I2C0_SCL; a5 SYS_RIO[9]; a6 PROC_RIO[9]; a7 PIO[9]; a8 SPI4_MISO |
| 10 | 19 | a0 SPI0_SIO[0]; a1 DPI_D[6]; a2 UART3_CTS; a3 I2C1_SDA; a5 SYS_RIO[10]; a6 PROC_RIO[10]; a7 PIO[10]; a8 SPI4_MOSI |
| 11 | 23 | a0 SPI0_SCLK; a1 DPI_D[7]; a2 UART3_RTS; a3 I2C1_SCL; a5 SYS_RIO[11]; a6 PROC_RIO[11]; a7 PIO[11]; a8 SPI4_SCLK |
| 12 | 32 | a0 PWM0[0]; a1 DPI_D[8]; a2 UART4_TX; a3 I2C2_SDA; a4 AUDIO_OUT_L; a5 SYS_RIO[12]; a6 PROC_RIO[12]; a7 PIO[12]; a8 SPI5_CSn[0] |
| 13 | 33 | a0 PWM0[1]; a1 DPI_D[9]; a2 UART4_RX; a3 I2C2_SCL; a4 AUDIO_OUT_R; a5 SYS_RIO[13]; a6 PROC_RIO[13]; a7 PIO[13]; a8 SPI5_SIO[1] |
| 14 | 8 | a0 PWM0[2]; a1 DPI_D[10]; a2 UART4_CTS; a3 I2C3_SDA; a4 UART0_TX; a5 SYS_RIO[14]; a6 PROC_RIO[14]; a7 PIO[14]; a8 SPI5_SIO[0] |
| 15 | 10 | a0 PWM0[3]; a1 DPI_D[11]; a2 UART4_RTS; a3 I2C3_SCL; a4 UART0_RX; a5 SYS_RIO[15]; a6 PROC_RIO[15]; a7 PIO[15]; a8 SPI5_SCLK |
| 16 | 36 | a0 SPI1_CSn[2]; a1 DPI_D[12]; a2 UART0_CTS; a5 SYS_RIO[16]; a6 PROC_RIO[16]; a7 PIO[16] |
| 17 | 11 | a0 SPI1_CSn[1]; a1 DPI_D[13]; a2 UART0_RTS; a5 SYS_RIO[17]; a6 PROC_RIO[17]; a7 PIO[17] |
| 18 | 12 | a0 SPI1_CSn[0]; a1 DPI_D[14]; a2 I2S0_SCLK; a3 PWM0[2]; a4 I2S1_SCLK; a5 SYS_RIO[18]; a6 PROC_RIO[18]; a7 PIO[18]; a8 GPCLK[1] |
| 19 | 35 | a0 SPI1_SIO[1]; a1 DPI_D[15]; a2 I2S0_WS; a3 PWM0[3]; a4 I2S1_WS; a5 SYS_RIO[19]; a6 PROC_RIO[19]; a7 PIO[19] |
| 20 | 38 | a0 SPI1_SIO[0]; a1 DPI_D[16]; a2 I2S0_SDI[0]; a3 GPCLK[0]; a4 I2S1_SDI[0]; a5 SYS_RIO[20]; a6 PROC_RIO[20]; a7 PIO[20] |
| 21 | 40 | a0 SPI1_SCLK; a1 DPI_D[17]; a2 I2S0_SDO[0]; a3 GPCLK[1]; a4 I2S1_SDO[0]; a5 SYS_RIO[21]; a6 PROC_RIO[21]; a7 PIO[21] |
| 22 | 15 | a0 SDIO0_CLK; a1 DPI_D[18]; a2 I2S0_SDI[1]; a3 I2C3_SDA; a4 I2S1_SDI[1]; a5 SYS_RIO[22]; a6 PROC_RIO[22]; a7 PIO[22] |
| 23 | 16 | a0 SDIO0_CMD; a1 DPI_D[19]; a2 I2S0_SDO[1]; a3 I2C3_SCL; a4 I2S1_SDO[1]; a5 SYS_RIO[23]; a6 PROC_RIO[23]; a7 PIO[23] |
| 24 | 18 | a0 SDIO0_DAT[0]; a1 DPI_D[20]; a2 I2S0_SDI[2]; a4 I2S1_SDI[2]; a5 SYS_RIO[24]; a6 PROC_RIO[24]; a7 PIO[24]; a8 SPI2_CSn[1] |
| 25 | 22 | a0 SDIO0_DAT[1]; a1 DPI_D[21]; a2 I2S0_SDO[2]; a3 AUDIO_IN_CLK; a4 I2S1_SDO[2]; a5 SYS_RIO[25]; a6 PROC_RIO[25]; a7 PIO[25]; a8 SPI3_CSn[1] |
| 26 | 37 | a0 SDIO0_DAT[2]; a1 DPI_D[22]; a2 I2S0_SDI[3]; a3 AUDIO_IN_DAT0; a4 I2S1_SDI[3]; a5 SYS_RIO[26]; a6 PROC_RIO[26]; a7 PIO[26]; a8 SPI5_CSn[1] |
| 27 | 13 | a0 SDIO0_DAT[3]; a1 DPI_D[23]; a2 I2S0_SDO[3]; a3 AUDIO_IN_DAT1; a4 I2S1_SDO[3]; a5 SYS_RIO[27]; a6 PROC_RIO[27]; a7 PIO[27]; a8 SPI1_CSn[1] |

### Mux rules and common buses

Each GPIO selects one function at a time. Assign a peripheral input to one GPIO only. If the same peripheral input is mapped to multiple GPIOs, the input receives their logical OR. Alternate functions also overlap across peripherals, so a GPIO assigned to one function is unavailable for its other functions.

| Peripheral | GPIO mapping options from the ros2_pc mux table |
| --- | --- |
| I2C0 | GPIO0/1 or GPIO8/9 |
| I2C1 | GPIO2/3 or GPIO10/11 |
| I2C2 | GPIO4/5 or GPIO12/13 |
| I2C3 | GPIO6/7, GPIO14/15, or GPIO22/23 |
| UART1 | TX/RX GPIO0/1; CTS/RTS GPIO2/3 |
| UART2 | TX/RX GPIO4/5; CTS/RTS GPIO6/7 |
| UART3 | TX/RX GPIO8/9; CTS/RTS GPIO10/11 |
| UART4 | TX/RX GPIO12/13; CTS/RTS GPIO14/15 |
| UART0 | TX/RX GPIO14/15; CTS/RTS GPIO16/17; DTR/RI GPIO5/4; DCD/DSR GPIO6/7; IrDA TX/RX GPIO3/2 |

For conventional SPI, SIO0 is MOSI and SIO1 is MISO. SPI0 uses GPIO8–11 for CE0, SIO0, SIO1, and SCLK in the common mapping; CE1 is GPIO7. The complete SPI alternate assignments, including the other controllers, are listed per GPIO above. The ros2_pc datasheet lists SPI0 as a four-chip-select Quad master, SPI1 as a three-chip-select Dual master, SPI2 and SPI3 as two-chip-select Dual masters, SPI4 as a single-chip-select Single slave, and SPI5 as a two-chip-select Dual master.

DPI uses GPIO0–27 for its clock, sync, and up to 24 data signals. SDIO uses GPIO22–27. I2S, PWM, audio, and clock outputs share pins with these and with the bus mappings above. GPIO0 and GPIO1 are the HAT identification signals `ID_SD` and `ID_SC`; they are also associated with MIPI1 I2C. The ros2_pc datasheet says they may be repurposed when that bus is unused, with `force_eeprom_read=0` in `config.txt` to stop the firmware from checking for a HAT EEPROM. The HAT+ specification reserves these pins for HAT identification.

The ros2_pc has additional RP1 GPIO signals that are not on J8. For example, GPIO29 is used for fan tachometer, GPIO34 and GPIO35 for camera control, GPIO38 and GPIO39 for MIPI0 I2C, and GPIO42 for USB VBUS enable. Do not treat these as J8 pins.

## Other connectors used for external devices

| Connector | Interface and pin information |
| --- | --- |
| CAM/DISP0 and CAM/DISP1 | Two 22-pin, 0.5 mm-pitch FFC connectors. Each carries four CSI-2 data lanes, a clock pair, two camera GPIOs, I2C, ground, and 3V3. Use the pin table below. CAM/DISP1 needs both J6 I2C jumpers fitted; it has no camera power-down signal. CAM/DISP0 has camera power-down support. |
| J14 fan | Four-pin, 1 mm-pitch JST-SH PWM fan connector. Pinout is listed below. It uses the 5 V rail. Some fans can run while ros2_pc is shut down because PWM stops. |
| USB-A | Two USB 3.0 host ports. Their VBUS current limit is approximately 1.2 A combined. |
| USB-C data | USB 2.0 data port, primarily for `rpiboot` and board updates. It is separate from the J11 power input. |
| J11 USB-C power | Main 5 V input. A compatible USB-C PD supply negotiates 5 V at 5 A. A standard Raspberry Pi 5 supply is also supported. |
| J8 5 V pins | J8 can also supply the board with external 5 V. The load depends on the ros2_pc and attached peripherals. Do not connect a second supply in parallel with J11 or PoE. |
| HDMI0 and HDMI1 | Two full-size HDMI 2.0 connectors. Their 5 V supply is current limited. |
| Ethernet RJ45 and J9 | Gigabit Ethernet with PoE support. The raw PoE signals route from the RJ45 magnetics to J9 for a PoE HAT. J9 is not a general-purpose power or GPIO connector. Use the revision-matched schematic for any carrier design; this page does not specify a custom PoE harness. |
| M.2 M-key | PCIe Gen 2 ×1 by default, 5 Gb/s, for standard M-key cards such as NVMe SSDs. PCIe Gen 3 ×1 is experimental and unsupported. Check card length, keying, power, and OS driver compatibility. |
| microSD | Available only with ros2_pc Lite modules without eMMC. |
| RTC battery | CR2032 battery socket for the real-time clock. |
| J2 | Boot, EEPROM write-protect, sync, PMIC enable, and wake/shutdown controls. See the pin table below. |
| J3 | Optional and not fitted by default. Three-pin Wi-Fi/Bluetooth disable header. See below. |

### CAM/DISP 22-pin FFC pinout

The signal names and directions below follow Raspberry Pi’s 22-pin camera connector reference. The data and clock pairs are MIPI D-PHY signals, not general-purpose logic pins. Pin 1 is marked by a small dot on ros2_pc IO Boards.

| Pin | Signal | Pin | Signal |
| ---: | --- | ---: | --- |
| 1 | GND | 2 | CAM_DN0 |
| 3 | CAM_DP0 | 4 | GND |
| 5 | CAM_DN1 | 6 | CAM_DP1 |
| 7 | GND | 8 | CAM_CN |
| 9 | CAM_CP | 10 | GND |
| 11 | CAM_DN2 | 12 | CAM_DP2 |
| 13 | GND | 14 | CAM_DN3 |
| 15 | CAM_DP3 | 16 | GND |
| 17 | CAM_IO0 / CAM_GPIO0 | 18 | CAM_IO1 / CAM_GPIO1 |
| 19 | GND | 20 | SCL |
| 21 | SDA | 22 | 3V3 |

The camera I2C lines are pulled up to 3.3 V on the board. The function and direction of `CAM_IO0` and `CAM_IO1` depend on the connected camera or display.

### J14 fan pinout

| Pin | Signal | Standard wire colour |
| ---: | --- | --- |
| 1 | +5V | Red |
| 2 | PWM | Blue |
| 3 | GND | Black |
| 4 | Tach | Yellow |

Raspberry Pi documents the fan header as a 1 mm-pitch JST-SH socket. ros2_pc IO Board Rev 2 adds a pull-up on the fan output for broader fan support. Treat PWM and tach as logic signals, not as power outputs.

### J2 and J3 control headers

| Header pin | Signal | Function |
| ---: | --- | --- |
| J2 1–2 | nRPIBOOT | Jumper forces USB boot instead of on-board eMMC. |
| J2 3–4 | EEPROM_nWP | Jumper write-protects the ros2_pc EEPROM. |
| J2 6 | SYNC_OUT | IEEE 1588 timing signal; may also be configured as an external timing input. |
| J2 12 | PMIC_ENABLE | Power-management control. |
| J2 13–14 | Wake/shutdown button | Connects an external push button for wake or shutdown. |
| J3 1 | WL_nDIS | Connect to J3 pin 2 (GND) to disable Wi-Fi. |
| J3 2 | GND | Ground reference for J3. |
| J3 3 | BT_nDIS | Connect to J3 pin 2 (GND) to disable Bluetooth. |

J6 has two jumpers that route I2C to CAM/DISP1. Fit both when using CAM/DISP1. The ros2_pc IO Board datasheet does not give a separate signal pinout for J6.

## Electrical limits

- The ros2_pc IO Board sets GPIO Vref to 3.3 V by default through R5. Moving R5 to R4 selects 1.8 V. Fit only one of R4 or R5; the change requires soldering.
- The ros2_pc datasheet limits the total load across all 28 GPIO pins to 50 mA. This is an aggregate limit, not a per-pin allowance. GPIO2 and GPIO3 have 1.8 kΩ pull-ups.
- The ros2_pc GPIO voltage must match Vref. Do not connect a 5 V logic output directly to J8. Use a suitable level shifter for signals above the selected Vref.
- The ros2_pc datasheet allows an externally generated 2.5 V GPIO_VREF only under specified power-sequencing and discharge conditions. This is not the ros2_pc IO Board’s R4/R5 selection and is not a stock-board wiring option.
- The two USB-A ports share an approximately 1.2 A VBUS limit. The fan also draws from the 5 V rail. USB and fan loads reduce current available elsewhere.
- J11 is the main power input. The board also permits a 5 V input through J8 and can receive 5 V through its PoE HAT path. Use one designed supply path; do not parallel independent power sources.
- J8 does not expose an ADC input. Use an external ADC for analog sensors.

The ros2_pc datasheet allows 600 mA from each 3.3 V and 1.8 V peripheral rail. That regulator capacity does not raise the separate 50 mA aggregate GPIO limit. The available current also depends on the chosen supply and the other board loads.

## Peripheral and controller details

The ros2_pc datasheet lists five UARTs, four I2C controllers, six SPI controllers, one 4-bit SDIO interface, four PWM channels, two I2S interfaces, two digital PDM audio inputs, two PWM audio outputs, two GPCLK outputs, and a 24-bit DPI interface. Many share J8 pins. The full per-pin table above is the source of truth when selecting a set of functions.

`SPI4` is device/slave mode; SPI0–SPI3 and SPI5 are master mode. Conventional SPI uses SIO0 as MOSI and SIO1 as MISO. The other SIO lanes support wider SPI modes.

The ros2_pc IO Board standard 40-pin header does not include the CM4-style extra 4-pin PoE header. ros2_pc IO Board routes PoE signals to J9 for the optional PoE HAT. Do not reuse a CM4 IO Board PoE header pinout.

## Sources

- ros2_pc IO Board datasheet, RP-008182, revision 2. See sections 2–5 and schematic figures on pages 12–14. The datasheet history lists the Rev 2 hardware changes on 1 August 2025. Product portal entry last checked 4 October 2026.
- ros2_pc datasheet, RP-008180, revision 6. See sections 2.6 and 2.9, Tables 1 and 2, and the GPIO power details.
- [ros2_pc IO Board Rev 2 KiCad design files](https://pip.raspberrypi.com/categories/1098-design-files). The product information portal lists the Rev 2 files as updated 6 October 2025.
- [Raspberry Pi 22-pin camera connector pinout](https://www.raspberrypi.com/documentation/accessories/camera.html#pinout-information).
- [Raspberry Pi HAT+ specification](https://datasheets.raspberrypi.com/hat/hat-plus-specification.pdf).
- [Raspberry Pi computer hardware documentation, Raspberry Pi 5 fan connector pinout](https://www.raspberrypi.com/documentation/computers/raspberry-pi.html#raspberry-pi-5-fan-connector-pinout).

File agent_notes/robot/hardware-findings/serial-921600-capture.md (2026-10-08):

# CH340 capture at 921600 baud produced corrupt rows

Follow-up setting: the user selected 576000 baud for current use after this capture and asked that the physical UART rate be measured in the future. No 576000-baud hardware measurement has been performed; treat it as provisional. A future firmware improvement could let captures select the channels they need to avoid transmitting unused data points. That software change is not part of this hardware observation.

## Observation

On 2026-10-07, the Navbot-ES02 was flashed with the diagnostic image and captured through `/dev/ttyUSB0`, identified as CH340 USB VID:PID `1a86:7523`. Serial MCP used 921600 baud, 8N1, no flow control, and DTR/RTS low. The diagnostic image keeps motor drivers disabled and skips balance and servo setup.

The raw byte capture is available locally at `/tmp/navbot-serial-rate-921600.bin` (900,000 bytes). It spans 95.54 seconds of device `time_us` timestamps, exceeding the requested 60 seconds.

## Evidence

- Valid CSV: 7,824 rows, each with 17 numeric fields; valid receive rate 81.89 rows/s.
- Device sequence span: 9,555 producer records over the timestamp span, or 100.01 records/s inferred from device IDs.
- Malformed numeric lines: 1,714; missing sequence IDs between valid rows: 1,731 across 125 detected gaps.
- Successive valid-row timestamp intervals: minimum/median/p95 10,000 µs; maximum 7,450,000 µs.
- Firmware snapshots reported zero queue drops and zero UART write failures.
- An earlier UTF-8 read attempt failed with an invalid byte sequence. The hex-mode capture contained 900,000 ASCII-range bytes but numerous missing separators and merged lines.

## Practical consequence and limits

Reception at 921600 baud is not reliable on the tested CH340/host/MCP path and is not accepted for data analysis. The zero firmware-side error counters and missing sequence IDs place the observed loss after producer enqueue and UART write accounting, but do not isolate whether the CH340 bridge, physical connection, host driver, or MCP capture decoder is responsible. No lower-baud comparison was run, and no baud fallback was added.

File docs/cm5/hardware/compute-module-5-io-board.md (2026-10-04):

# Raspberry Pi Compute Module 5 IO Board pinout

## Scope and status

This page is a manufacturer reference for the Raspberry Pi Compute Module 5 IO Board (CM5IO), the standard carrier shown in the cited Raspberry Pi documents. It does not confirm that the project has selected, bought, inspected, or installed a CM5IO. The project’s CM5 hardware remains pending.

The current Raspberry Pi IO Board datasheet is document RP-008182, revision 2. Its history records the Rev 2 hardware changes dated 1 August 2025. Raspberry Pi’s design-files page lists the Rev 2 KiCad files, updated 6 October 2025. The product portal identifies the IO Board as SC1751 and SC1967. Check the revision printed on the physical board before using this reference for wiring. See the [CM5IO datasheet](https://pip-assets.raspberrypi.com/categories/1097-raspberry-pi-compute-module-5-io-board/documents/RP-008182-DS-2-cm5io-datasheet.pdf), [CM5IO Rev 2 design files](https://pip.raspberrypi.com/categories/1098-design-files), and [CM5IO product page](https://www.raspberrypi.com/products/compute-module-5-io-board/).

The GPIO alternate functions below come from the [Compute Module 5 datasheet](https://pip-assets.raspberrypi.com/categories/944-raspberry-pi-compute-module-5/documents/RP-008180-DS-6-cm5-datasheet.pdf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), Table 1. They describe the CM5/RP1 mux, not a promise that every function is enabled in the project’s operating system. The board-specific connector and configuration details come from the CM5IO datasheet. Raspberry Pi’s [camera connector pinout](https://www.raspberrypi.com/documentation/accessories/camera.html#pinout-information) and [40-pin HAT+ specification](https://datasheets.raspberrypi.com/hat/hat-plus-specification.pdf) provide connector orientation and standard-header context.

## GPIO header J8

J8 is the standard 40-pin, 2 × 20, 2.54 mm-pitch Raspberry Pi header. Physical pin numbers below follow the standard HAT+ numbering. Use the pin 1 marker on the board and the board drawing when locating pins; do not infer pin 1 from a cable view.

| Physical pins, odd column | Signal | Physical pins, even column | Signal |
| ---: | --- | ---: | --- |
| 1 | 3V3 | 2 | 5V |
| 3 | GPIO2 / I2C1 SDA | 4 | 5V |
| 5 | GPIO3 / I2C1 SCL | 6 | GND |
| 7 | GPIO4 | 8 | GPIO14 / UART0 TX |
| 9 | GND | 10 | GPIO15 / UART0 RX |
| 11 | GPIO17 | 12 | GPIO18 |
| 13 | GPIO27 | 14 | GND |
| 15 | GPIO22 | 16 | GPIO23 |
| 17 | 3V3 | 18 | GPIO24 |
| 19 | GPIO10 / SPI0 SIO0 (MOSI) | 20 | GND |
| 21 | GPIO9 / SPI0 SIO1 (MISO) | 22 | GPIO25 |
| 23 | GPIO11 / SPI0 SCLK | 24 | GPIO8 / SPI0 CE0 |
| 25 | GND | 26 | GPIO7 / SPI0 CE1 |
| 27 | GPIO0 / ID_SD | 28 | GPIO1 / ID_SC |
| 29 | GPIO5 | 30 | GND |
| 31 | GPIO6 | 32 | GPIO12 |
| 33 | GPIO13 | 34 | GND |
| 35 | GPIO19 | 36 | GPIO16 |
| 37 | GPIO26 | 38 | GPIO20 |
| 39 | GND | 40 | GPIO21 |

The bus names in the table are common mappings, not fixed assignments. The complete documented mux options follow. `a0` through `a8` are the alternate-function selector values from Table 1 of the CM5 datasheet. A selector omitted from a row has no named function in that table and is reserved.

| GPIO | J8 pin | Alternate functions |
| ---: | ---: | --- |
| 0 | 27 | a0 SPI0_SIO[3]; a1 DPI_PCLK; a2 UART1_TX; a3 I2C0_SDA; a5 SYS_RIO[0]; a6 PROC_RIO[0]; a7 PIO[0]; a8 SPI2_CSn[0] |
| 1 | 28 | a0 SPI0_SIO[2]; a1 DPI_DE; a2 UART1_RX; a3 I2C0_SCL; a5 SYS_RIO[1]; a6 PROC_RIO[1]; a7 PIO[1]; a8 SPI2_SIO[1] |
| 2 | 3 | a0 SPI0_CSn[3]; a1 DPI_VSYNC; a2 UART1_CTS; a3 I2C1_SDA; a4 UART0_IR_RX; a5 SYS_RIO[2]; a6 PROC_RIO[2]; a7 PIO[2]; a8 SPI2_SIO[0] |
| 3 | 5 | a0 SPI0_CSn[2]; a1 DPI_HSYNC; a2 UART1_RTS; a3 I2C1_SCL; a4 UART0_IR_TX; a5 SYS_RIO[3]; a6 PROC_RIO[3]; a7 PIO[3]; a8 SPI2_SCLK |
| 4 | 7 | a0 GPCLK[0]; a1 DPI_D[0]; a2 UART2_TX; a3 I2C2_SDA; a4 UART0_RI; a5 SYS_RIO[4]; a6 PROC_RIO[4]; a7 PIO[4]; a8 SPI3_CSn[0] |
| 5 | 29 | a0 GPCLK[1]; a1 DPI_D[1]; a2 UART2_RX; a3 I2C2_SCL; a4 UART0_DTR; a5 SYS_RIO[5]; a6 PROC_RIO[5]; a7 PIO[5]; a8 SPI3_SIO[1] |
| 6 | 31 | a0 GPCLK[2]; a1 DPI_D[2]; a2 UART2_CTS; a3 I2C3_SDA; a4 UART0_DCD; a5 SYS_RIO[6]; a6 PROC_RIO[6]; a7 PIO[6]; a8 SPI3_SIO[0] |
| 7 | 26 | a0 SPI0_CSn[1]; a1 DPI_D[3]; a2 UART2_RTS; a3 I2C3_SCL; a4 UART0_DSR; a5 SYS_RIO[7]; a6 PROC_RIO[7]; a7 PIO[7]; a8 SPI3_SCLK |
| 8 | 24 | a0 SPI0_CSn[0]; a1 DPI_D[4]; a2 UART3_TX; a3 I2C0_SDA; a5 SYS_RIO[8]; a6 PROC_RIO[8]; a7 PIO[8]; a8 SPI4_CSn[0] |
| 9 | 21 | a0 SPI0_SIO[1]; a1 DPI_D[5]; a2 UART3_RX; a3 I2C0_SCL; a5 SYS_RIO[9]; a6 PROC_RIO[9]; a7 PIO[9]; a8 SPI4_MISO |
| 10 | 19 | a0 SPI0_SIO[0]; a1 DPI_D[6]; a2 UART3_CTS; a3 I2C1_SDA; a5 SYS_RIO[10]; a6 PROC_RIO[10]; a7 PIO[10]; a8 SPI4_MOSI |
| 11 | 23 | a0 SPI0_SCLK; a1 DPI_D[7]; a2 UART3_RTS; a3 I2C1_SCL; a5 SYS_RIO[11]; a6 PROC_RIO[11]; a7 PIO[11]; a8 SPI4_SCLK |
| 12 | 32 | a0 PWM0[0]; a1 DPI_D[8]; a2 UART4_TX; a3 I2C2_SDA; a4 AUDIO_OUT_L; a5 SYS_RIO[12]; a6 PROC_RIO[12]; a7 PIO[12]; a8 SPI5_CSn[0] |
| 13 | 33 | a0 PWM0[1]; a1 DPI_D[9]; a2 UART4_RX; a3 I2C2_SCL; a4 AUDIO_OUT_R; a5 SYS_RIO[13]; a6 PROC_RIO[13]; a7 PIO[13]; a8 SPI5_SIO[1] |
| 14 | 8 | a0 PWM0[2]; a1 DPI_D[10]; a2 UART4_CTS; a3 I2C3_SDA; a4 UART0_TX; a5 SYS_RIO[14]; a6 PROC_RIO[14]; a7 PIO[14]; a8 SPI5_SIO[0] |
| 15 | 10 | a0 PWM0[3]; a1 DPI_D[11]; a2 UART4_RTS; a3 I2C3_SCL; a4 UART0_RX; a5 SYS_RIO[15]; a6 PROC_RIO[15]; a7 PIO[15]; a8 SPI5_SCLK |
| 16 | 36 | a0 SPI1_CSn[2]; a1 DPI_D[12]; a2 UART0_CTS; a5 SYS_RIO[16]; a6 PROC_RIO[16]; a7 PIO[16] |
| 17 | 11 | a0 SPI1_CSn[1]; a1 DPI_D[13]; a2 UART0_RTS; a5 SYS_RIO[17]; a6 PROC_RIO[17]; a7 PIO[17] |
| 18 | 12 | a0 SPI1_CSn[0]; a1 DPI_D[14]; a2 I2S0_SCLK; a3 PWM0[2]; a4 I2S1_SCLK; a5 SYS_RIO[18]; a6 PROC_RIO[18]; a7 PIO[18]; a8 GPCLK[1] |
| 19 | 35 | a0 SPI1_SIO[1]; a1 DPI_D[15]; a2 I2S0_WS; a3 PWM0[3]; a4 I2S1_WS; a5 SYS_RIO[19]; a6 PROC_RIO[19]; a7 PIO[19] |
| 20 | 38 | a0 SPI1_SIO[0]; a1 DPI_D[16]; a2 I2S0_SDI[0]; a3 GPCLK[0]; a4 I2S1_SDI[0]; a5 SYS_RIO[20]; a6 PROC_RIO[20]; a7 PIO[20] |
| 21 | 40 | a0 SPI1_SCLK; a1 DPI_D[17]; a2 I2S0_SDO[0]; a3 GPCLK[1]; a4 I2S1_SDO[0]; a5 SYS_RIO[21]; a6 PROC_RIO[21]; a7 PIO[21] |
| 22 | 15 | a0 SDIO0_CLK; a1 DPI_D[18]; a2 I2S0_SDI[1]; a3 I2C3_SDA; a4 I2S1_SDI[1]; a5 SYS_RIO[22]; a6 PROC_RIO[22]; a7 PIO[22] |
| 23 | 16 | a0 SDIO0_CMD; a1 DPI_D[19]; a2 I2S0_SDO[1]; a3 I2C3_SCL; a4 I2S1_SDO[1]; a5 SYS_RIO[23]; a6 PROC_RIO[23]; a7 PIO[23] |
| 24 | 18 | a0 SDIO0_DAT[0]; a1 DPI_D[20]; a2 I2S0_SDI[2]; a4 I2S1_SDI[2]; a5 SYS_RIO[24]; a6 PROC_RIO[24]; a7 PIO[24]; a8 SPI2_CSn[1] |
| 25 | 22 | a0 SDIO0_DAT[1]; a1 DPI_D[21]; a2 I2S0_SDO[2]; a3 AUDIO_IN_CLK; a4 I2S1_SDO[2]; a5 SYS_RIO[25]; a6 PROC_RIO[25]; a7 PIO[25]; a8 SPI3_CSn[1] |
| 26 | 37 | a0 SDIO0_DAT[2]; a1 DPI_D[22]; a2 I2S0_SDI[3]; a3 AUDIO_IN_DAT0; a4 I2S1_SDI[3]; a5 SYS_RIO[26]; a6 PROC_RIO[26]; a7 PIO[26]; a8 SPI5_CSn[1] |
| 27 | 13 | a0 SDIO0_DAT[3]; a1 DPI_D[23]; a2 I2S0_SDO[3]; a3 AUDIO_IN_DAT1; a4 I2S1_SDO[3]; a5 SYS_RIO[27]; a6 PROC_RIO[27]; a7 PIO[27]; a8 SPI1_CSn[1] |

### Mux rules and common buses

Each GPIO selects one function at a time. Assign a peripheral input to one GPIO only. If the same peripheral input is mapped to multiple GPIOs, the input receives their logical OR. Alternate functions also overlap across peripherals, so a GPIO assigned to one function is unavailable for its other functions.

| Peripheral | GPIO mapping options from the CM5 mux table |
| --- | --- |
| I2C0 | GPIO0/1 or GPIO8/9 |
| I2C1 | GPIO2/3 or GPIO10/11 |
| I2C2 | GPIO4/5 or GPIO12/13 |
| I2C3 | GPIO6/7, GPIO14/15, or GPIO22/23 |
| UART1 | TX/RX GPIO0/1; CTS/RTS GPIO2/3 |
| UART2 | TX/RX GPIO4/5; CTS/RTS GPIO6/7 |
| UART3 | TX/RX GPIO8/9; CTS/RTS GPIO10/11 |
| UART4 | TX/RX GPIO12/13; CTS/RTS GPIO14/15 |
| UART0 | TX/RX GPIO14/15; CTS/RTS GPIO16/17; DTR/RI GPIO5/4; DCD/DSR GPIO6/7; IrDA TX/RX GPIO3/2 |

For conventional SPI, SIO0 is MOSI and SIO1 is MISO. SPI0 uses GPIO8–11 for CE0, SIO0, SIO1, and SCLK in the common mapping; CE1 is GPIO7. The complete SPI alternate assignments, including the other controllers, are listed per GPIO above. The CM5 datasheet lists SPI0 as a four-chip-select Quad master, SPI1 as a three-chip-select Dual master, SPI2 and SPI3 as two-chip-select Dual masters, SPI4 as a single-chip-select Single slave, and SPI5 as a two-chip-select Dual master.

DPI uses GPIO0–27 for its clock, sync, and up to 24 data signals. SDIO uses GPIO22–27. I2S, PWM, audio, and clock outputs share pins with these and with the bus mappings above. GPIO0 and GPIO1 are the HAT identification signals `ID_SD` and `ID_SC`; they are also associated with MIPI1 I2C. The CM5 datasheet says they may be repurposed when that bus is unused, with `force_eeprom_read=0` in `config.txt` to stop the firmware from checking for a HAT EEPROM. The HAT+ specification reserves these pins for HAT identification.

The CM5 has additional RP1 GPIO signals that are not on J8. For example, GPIO29 is used for fan tachometer, GPIO34 and GPIO35 for camera control, GPIO38 and GPIO39 for MIPI0 I2C, and GPIO42 for USB VBUS enable. Do not treat these as J8 pins.

## Other connectors used for external devices

| Connector | Interface and pin information |
| --- | --- |
| CAM/DISP0 and CAM/DISP1 | Two 22-pin, 0.5 mm-pitch FFC connectors. Each carries four CSI-2 data lanes, a clock pair, two camera GPIOs, I2C, ground, and 3V3. Use the pin table below. CAM/DISP1 needs both J6 I2C jumpers fitted; it has no camera power-down signal. CAM/DISP0 has camera power-down support. |
| J14 fan | Four-pin, 1 mm-pitch JST-SH PWM fan connector. Pinout is listed below. It uses the 5 V rail. Some fans can run while CM5 is shut down because PWM stops. |
| USB-A | Two USB 3.0 host ports. Their VBUS current limit is approximately 1.2 A combined. |
| USB-C data | USB 2.0 data port, primarily for `rpiboot` and board updates. It is separate from the J11 power input. |
| J11 USB-C power | Main 5 V input. A compatible USB-C PD supply negotiates 5 V at 5 A. A standard Raspberry Pi 5 supply is also supported. |
| J8 5 V pins | J8 can also supply the board with external 5 V. The load depends on the CM5 and attached peripherals. Do not connect a second supply in parallel with J11 or PoE. |
| HDMI0 and HDMI1 | Two full-size HDMI 2.0 connectors. Their 5 V supply is current limited. |
| Ethernet RJ45 and J9 | Gigabit Ethernet with PoE support. The raw PoE signals route from the RJ45 magnetics to J9 for a PoE HAT. J9 is not a general-purpose power or GPIO connector. Use the revision-matched schematic for any carrier design; this page does not specify a custom PoE harness. |
| M.2 M-key | PCIe Gen 2 ×1 by default, 5 Gb/s, for standard M-key cards such as NVMe SSDs. PCIe Gen 3 ×1 is experimental and unsupported. Check card length, keying, power, and OS driver compatibility. |
| microSD | Available only with CM5 Lite modules without eMMC. |
| RTC battery | CR2032 battery socket for the real-time clock. |
| J2 | Boot, EEPROM write-protect, sync, PMIC enable, and wake/shutdown controls. See the pin table below. |
| J3 | Optional and not fitted by default. Three-pin Wi-Fi/Bluetooth disable header. See below. |

### CAM/DISP 22-pin FFC pinout

The signal names and directions below follow Raspberry Pi’s 22-pin camera connector reference. The data and clock pairs are MIPI D-PHY signals, not general-purpose logic pins. Pin 1 is marked by a small dot on CM5 IO Boards.

| Pin | Signal | Pin | Signal |
| ---: | --- | ---: | --- |
| 1 | GND | 2 | CAM_DN0 |
| 3 | CAM_DP0 | 4 | GND |
| 5 | CAM_DN1 | 6 | CAM_DP1 |
| 7 | GND | 8 | CAM_CN |
| 9 | CAM_CP | 10 | GND |
| 11 | CAM_DN2 | 12 | CAM_DP2 |
| 13 | GND | 14 | CAM_DN3 |
| 15 | CAM_DP3 | 16 | GND |
| 17 | CAM_IO0 / CAM_GPIO0 | 18 | CAM_IO1 / CAM_GPIO1 |
| 19 | GND | 20 | SCL |
| 21 | SDA | 22 | 3V3 |

The camera I2C lines are pulled up to 3.3 V on the board. The function and direction of `CAM_IO0` and `CAM_IO1` depend on the connected camera or display.

### J14 fan pinout

| Pin | Signal | Standard wire colour |
| ---: | --- | --- |
| 1 | +5V | Red |
| 2 | PWM | Blue |
| 3 | GND | Black |
| 4 | Tach | Yellow |

Raspberry Pi documents the fan header as a 1 mm-pitch JST-SH socket. CM5IO Rev 2 adds a pull-up on the fan output for broader fan support. Treat PWM and tach as logic signals, not as power outputs.

### J2 and J3 control headers

| Header pin | Signal | Function |
| ---: | --- | --- |
| J2 1–2 | nRPIBOOT | Jumper forces USB boot instead of on-board eMMC. |
| J2 3–4 | EEPROM_nWP | Jumper write-protects the CM5 EEPROM. |
| J2 6 | SYNC_OUT | IEEE 1588 timing signal; may also be configured as an external timing input. |
| J2 12 | PMIC_ENABLE | Power-management control. |
| J2 13–14 | Wake/shutdown button | Connects an external push button for wake or shutdown. |
| J3 1 | WL_nDIS | Connect to J3 pin 2 (GND) to disable Wi-Fi. |
| J3 2 | GND | Ground reference for J3. |
| J3 3 | BT_nDIS | Connect to J3 pin 2 (GND) to disable Bluetooth. |

J6 has two jumpers that route I2C to CAM/DISP1. Fit both when using CAM/DISP1. The CM5IO datasheet does not give a separate signal pinout for J6.

## Electrical limits

- The CM5IO sets GPIO Vref to 3.3 V by default through R5. Moving R5 to R4 selects 1.8 V. Fit only one of R4 or R5; the change requires soldering.
- The CM5 datasheet limits the total load across all 28 GPIO pins to 50 mA. This is an aggregate limit, not a per-pin allowance. GPIO2 and GPIO3 have 1.8 kΩ pull-ups.
- The CM5 GPIO voltage must match Vref. Do not connect a 5 V logic output directly to J8. Use a suitable level shifter for signals above the selected Vref.
- The CM5 datasheet allows an externally generated 2.5 V GPIO_VREF only under specified power-sequencing and discharge conditions. This is not the CM5IO’s R4/R5 selection and is not a stock-board wiring option.
- The two USB-A ports share an approximately 1.2 A VBUS limit. The fan also draws from the 5 V rail. USB and fan loads reduce current available elsewhere.
- J11 is the main power input. The board also permits a 5 V input through J8 and can receive 5 V through its PoE HAT path. Use one designed supply path; do not parallel independent power sources.
- J8 does not expose an ADC input. Use an external ADC for analog sensors.

The CM5 datasheet allows 600 mA from each 3.3 V and 1.8 V peripheral rail. That regulator capacity does not raise the separate 50 mA aggregate GPIO limit. The available current also depends on the chosen supply and the other board loads.

## Peripheral and controller details

The CM5 datasheet lists five UARTs, four I2C controllers, six SPI controllers, one 4-bit SDIO interface, four PWM channels, two I2S interfaces, two digital PDM audio inputs, two PWM audio outputs, two GPCLK outputs, and a 24-bit DPI interface. Many share J8 pins. The full per-pin table above is the source of truth when selecting a set of functions.

`SPI4` is device/slave mode; SPI0–SPI3 and SPI5 are master mode. Conventional SPI uses SIO0 as MOSI and SIO1 as MISO. The other SIO lanes support wider SPI modes.

The CM5IO standard 40-pin header does not include the CM4-style extra 4-pin PoE header. CM5IO routes PoE signals to J9 for the optional PoE HAT. Do not reuse a CM4 IO Board PoE header pinout.

## Sources

- [Raspberry Pi Compute Module 5 IO Board datasheet, RP-008182, revision 2](https://pip-assets.raspberrypi.com/categories/1097-raspberry-pi-compute-module-5-io-board/documents/RP-008182-DS-2-cm5io-datasheet.pdf). See sections 2–5 and schematic figures on pages 12–14. The datasheet history lists the Rev 2 hardware changes on 1 August 2025. Product portal entry last checked 4 October 2026.
- [Raspberry Pi Compute Module 5 datasheet, RP-008180, revision 6](https://pip-assets.raspberrypi.com/categories/944-raspberry-pi-compute-module-5/documents/RP-008180-DS-6-cm5-datasheet.pdf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). See sections 2.6 and 2.9, Tables 1 and 2, and the GPIO power details.
- [CM5 IO Board Rev 2 KiCad design files](https://pip.raspberrypi.com/categories/1098-design-files). The product information portal lists the Rev 2 files as updated 6 October 2025.
- [Raspberry Pi 22-pin camera connector pinout](https://www.raspberrypi.com/documentation/accessories/camera.html#pinout-information).
- [Raspberry Pi HAT+ specification](https://datasheets.raspberrypi.com/hat/hat-plus-specification.pdf).
- [Raspberry Pi computer hardware documentation, Raspberry Pi 5 fan connector pinout](https://www.raspberrypi.com/documentation/computers/raspberry-pi.html#raspberry-pi-5-fan-connector-pinout).

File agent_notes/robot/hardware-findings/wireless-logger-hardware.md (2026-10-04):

# Wireless logger hardware finding

The user confirmed on 2026-09-28 that the assembled board uses ESP32-S3-WROOM-1 without external RAM and that its pin assignment is correct. The exported PCB netlist labels U4 as ESP32-S3-WROOM-1-N8R8 while assigning GPIO35–37 to other signals. Treat the user's assembly confirmation as the hardware fact and retain the netlist label as a design discrepancy.

The practical consequence is to budget internal SRAM and leave PSRAM disabled. The free buffer capacity under firmware and Wi-Fi load remains unmeasured. The IMU interrupt pins appear in the U5 symbol but are not connected to U4 in the exported netlist; inspect the physical board before planning interrupt-based FIFO capture.

The full hardware constraints and source distinctions are documented in [docs/robot/hardware/wireless-logging-constraints.md](../../../docs/robot/hardware/wireless-logging-constraints.md).

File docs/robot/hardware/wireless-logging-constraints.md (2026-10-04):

# Hardwarebefunde für kabelloses Logging

Stand 28.09.2026; Dokumentenvergleich und anschließende Hardwarekorrektur durch den Nutzer, keine eigene Messung.

## PSRAM und GPIO35–37

Beobachtung: [PCB-Netzliste](electronics/netlist.md), U4, nennt ESP32-S3-WROOM-1-N8R8 und verbindet zugleich IO35/36 mit LED2/3 sowie IO37 mit EN_B. Die Firmware verwendet diese GPIOs ebenfalls. Laut [Espressif-Datenblatt, Abschnitt 3, Fußnote b](https://documentation.espressif.com/esp32-s3-wroom-1_wroom-1u_datasheet_en.pdf) stehen IO35–37 bei Octal-PSRAM-Modulen nicht für andere Zwecke zur Verfügung.

**Korrektur durch den Nutzer am 28.09.2026:** Bestückt ist ESP32-S3-WROOM-1, es gibt keinen externen RAM, und die Pinbelegung ist korrekt. Dies ist die maßgebliche Angabe zum aufgebauten Roboter. Die N8R8-Bezeichnung der exportierten Netzliste bleibt als abweichende Designangabe erhalten; daraus keinen realen PSRAM-Pinkonflikt ableiten.

Konsequenz: Mit internem SRAM planen, PSRAM deaktiviert lassen und keine Pinänderung vorsehen. Die tatsächlich freie interne Pufferkapazität unter Firmware-/WLAN-Last muss noch gemessen werden. Die Flashgröße ist aus der Basisbezeichnung allein nicht bestimmt.

## IMU-Interrupts

Beobachtung: Die exportierte U5-Belegung enthält INT1/INT2, U4 aber keine entsprechenden Netze; R28 zieht INT2 mit 10 kΩ nach GND. Der vorhandene IMU-Treiber liest Datenregister über SPI und nutzt keinen FIFO-/Interruptpfad.

Konsequenz: Kein vorhandener ESP-Interruptanschluss annehmen. Für FIFO-Erfassung entweder begrenztes Polling entwickeln oder nach Prüfung von Layout und realer Platine einen geeigneten Anschluss planen.

Das [Konzept](../software/proposals/wifi-logging/concept.md) beschreibt Speicherbudget und Entscheidungspunkte.

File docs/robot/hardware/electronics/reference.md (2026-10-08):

# Elektronik-Hardware: technische Referenz

Diese Seite ergänzt die [Systemübersicht](../system-overview.md); alle Bauteil-Pads und Netze stehen in der [Bauteil-Netzliste](netlist.md). **Pins sind physische Steckerkontakte laut EasyEDA-PCB-Netzliste**, GPIOs sind ESP32-S3-Nummern laut Schaltplansymbol und Firmware. Die Kontaktansicht und Kabelrichtung sind damit noch nicht festgelegt; vor dem Einstecken die Platinenbeschriftung prüfen. `MAIN` und `CODER` sind die zwei Boards in `project.json` des [EasyEDA-Projekts](../../../../hardware/pcb/ProPrj_NavBot-ES02.epro).

## Stromversorgung

**Bestückung laut Nutzer, 28.09.2026:** ESP32-S3-WROOM-1 ohne externen RAM; vorhandene Pinbelegung korrekt. Die N8R8-Angabe der Netzliste beschreibt nicht die bestätigte RAM-Ausstattung. Mit internem SRAM planen, PSRAM nicht aktivieren. Quellenabgrenzung und separate IMU-Interruptfrage: [wireless-logging constraints](../wireless-logging-constraints.md).

| Stufe | Bauteile / Netze | Funktion und praktische Folge |
| --- | --- | --- |
| Akku | Externer 2S-18650-Halter → `CN2`: 1 `B2`, 2 `B1`, 3 `B-` | Mittelabgriff `B1`; nicht mit einer einfachen zweipoligen Akkuleitung verwechseln. BOM: ein 2S-Halter und zwei Zellen. |
| Schutz und Ein/Aus | `U8` HY2120-LB, `Q2` WSD3056DN, `SW4`/`SW1`; `SW1` führt `B2` nach `VIN` | Zellschutz und geschaltete Hauptversorgung sind im Design vorhanden. `VIN` versorgt die Motortreiber direkt. Die tatsächliche Abschaltschwelle wurde hier nicht gemessen. |
| Laden / USB | `M1` „2S充电模块“ mit `VBUS`, `B2`, `B1`, `GND`, `VSTA`; USB-C `USB1`; `D5`/`J1` im Pfad zu `+5V` | Laden und USB-Versorgung sind im Design vorgesehen. Kein Ladeverhalten oder gleichzeitiger Betrieb unter Last wurde verifiziert. `VSTA` geht zum ESP32 (`GPIO18`). |
| 5 V | `U1` RT8289GSP, `L1` FXL0630-100-M, Eingangsnetz `VIN`, Ausgang `+5V` | Schaltregler für 5-V-Verbraucher/Anschlüsse. |
| 3,3 V | `U2` XC6210B332MR von `+5V` nach `+3.3V` | Versorgt ESP32, IMU, Encoder und Logik; nicht die Servolast. |
| Servo-Versorgung | `H11`: 1 `+5V`, 2 Servo-Versorgungsnetz, 3 `VIN`; dasselbe Netz an `H9/H10` Pins 3/4 | Dreipolige Auswahl: Brücke 1–2 = 5 V, 2–3 = VIN. Welche Brücke physisch steckt, ist nicht aus dem PCB-Projekt ableitbar. Vor 2S-VIN an Servos deren Zulässigkeit prüfen. |
| Batteriespannung | `R1` 10 kΩ von `VIN` nach `ADC`, `R2` 1 kΩ nach GND, `C1` 100 nF; `ADC` → ESP32 `GPIO17` | Spannungsteiler ca. 1:11. `ReadVoltage()` nutzt eine lokale Kalibrierung `7.77 / 813.43 × ADC`; dieser Schätzwert ist kein direkter 3,3-V- oder Zell-Einzelwert. |

**Prüfpunkt 5-V-Regler:** Im PCB-Netzlistenexport ist Pin 5 (`EN`) des RT8289 `U1` als unverbunden markiert. Die Netzliste allein klärt nicht, ob ein interner Default, eine abweichende reale Bestückung oder ein Designfehler vorliegt. Bei fehlenden 5 V zuerst diesen Punkt am realen Board und mit dem Bauteildatenblatt prüfen; aus der vorhandenen Board-Beobachtung folgt keine Pin-5-Messung.

## Motoren und Encoder

| Kanal | MAIN-Netze / GPIO | Peripherie |
| --- | --- | --- |
| A / `motor1` | `U6` MP6536; `PWM1_A/2_A/3_A` = GPIO15/7/6, `EN_A` = GPIO16; `H7` Pins 1/2/3 = `U_A/V_A/W_A` | Dreiphasiger Radmotor; Firmware `BLDCDriver3PWM(15, 7, 6, 16)`. |
| B / `motor2` | `U7` MP6536; `PWM1_B/2_B/3_B` = GPIO40/39/38, `EN_B` = GPIO37; `H8` Pins 1/2/3 = `U_B/V_B/W_B` | Zweiter dreiphasiger Radmotor; Firmware `BLDCDriver3PWM(40, 39, 38, 37)`. |
| Encoder A | `H5` Pins 1 SDA = GPIO4, 2 SCL = GPIO5, 3 GND, 4 +3,3 V; 5/6 GND laut PCB-Pads | `I2Cone.begin(4, 5, 400000)` und `sensor1` AS5600. Pins 5/6 gehören nicht zum vieradrigen Kabel. |
| Encoder B | `H6` Pins 1 SDA = GPIO41, 2 SCL = GPIO42, 3 GND, 4 +3,3 V; 5/6 GND laut PCB-Pads | `I2Ctwo.begin(41, 42, 400000)` und `sensor2` AS5600. Pins 5/6 gehören nicht zum vieradrigen Kabel. |

Die kleine **CODER**-Platine enthält `U1` AS5600-ASOM, lokale 3,3-V-Abblockung und 10-kΩ-Pull-ups für SDA/SCL. Deren `H1` hat dieselbe logische Reihenfolge: 1 SDA, 2 SCL, 3 GND, 4 3,3 V; weitere Footprint-Pads 5/6 liegen an GND und sind keine zusätzlichen Kabeladern. Der MAIN-Pull-up ist je I²C-Leitung 3,3 kΩ. Die BOM nennt zwei AS5600-Module, zwei 2208-90-kV-Motoren und zwei radiale 6 × 1,5-mm-Magnete. Magnetposition und elektrischer Nullwinkel müssen mechanisch/mit SimpleFOC kalibriert werden; sie folgen nicht aus der Netzliste.

**Polpaare, Recherche vom 01.10.2026:** Die [SimpleFOC-Motordokumentation](https://docs.simplefoc.com/bldc_motors) nennt für den 2208-90KV-Gimbalmotor `12N14P`: 12 Statornuten und 14 Rotorpole, also **7 Polpaare**. Das passt zur Modellangabe `2208-90kv` in `BOM.xlsx`, `Sheet1!D26`. Beide Firmware-Instanzen verwenden bereits fest `BLDCMotor(7)`. Die verbauten Einzelmotoren wurden nicht durch Magnetzählung oder eine unabhängige Messung bestätigt; die BOM beschreibt die vorgesehenen Kaufteile.

Der [Startup-Mitschnitt nach dem Bibliothekswechsel](../../../../build/serial-startup-after-foc-update.txt) zeigt zwei erfolgreiche MCPWM-Initialisierungen und `Motor ready.`, aber Polpaar-Prüfschätzungen von 8,46 und 7,80. In der installierten SimpleFOC-Version 2.3.5 prüft `BLDCMotor::alignSensor()` den Winkelweg gegen den fest konfigurierten Wert und gibt bei Abweichung eine Schätzung aus; es überschreibt `pole_pairs` nicht. **Konsequenz:** 7 beibehalten und die Warnungen als offene Abweichung beim Abgleich behandeln. Aus diesem kurzen Abgleich allein weder 8 Polpaare ableiten noch die Warnung durch Überspringen der Kalibrierung unterdrücken. Eine Last, unvollständige Rotorbewegung oder ein Encoderfehler sind mögliche Ursachen, hier aber nicht nachgewiesen.

## Sensoren und Signale

| Funktion | Chip / Signal | ESP32-S3 und Firmware |
| --- | --- | --- |
| IMU | `U5` ICM-42688P-HXY, SPI `SCLK/MOSI/MISO/CS1` | GPIO3/9/10/13; `ICM42688.cpp` verwendet SPI Mode 3, Beschleunigung ±8 g und Gyro ±2000 °/s bei 1 kHz. `INT1/INT2` sind im Design vorhanden; die gezeigte Firmware liest per SPI. |
| Vier Beinservos | `SERVO1/2/3/4` | GPIO11/12/21/14, 50-Hz-PWM in `ServoControl`; Servo 2/3 sind in der Standard-Ansteuerung invertiert. Die GPIO-Reihenfolge sagt noch nichts über links/rechts an der Mechanik. |
| Betriebs-LEDs | `LED2/LED3` | GPIO35/36; `BOARD_PIN_LED=35` und LOW schaltet die Firmware-LED ein. |
| Ladesignal | `VSTA` | GPIO18; im Schaltplan an `M1`, ohne hier bestätigte Softwareauswertung. |
| Versionskennung | `VERSION_ADC` | GPIO8, Teiler 180 kΩ/100 kΩ; im Design vorhanden, Nutzung der aktuellen Firmware nicht belegt. |

## Anschlüsse

| Stecker | Physische Pins laut PCB | Zweck / Hinweis |
| --- | --- | --- |
| `CN2` | 1 `B2`, 2 `B1`, 3 `B-` | 2S-Akku mit Mittelabgriff. |
| `H4` | 1 GND, 2 +5 V, 3 SBUS-Eingang über `R12/Q1` | Externer RC-Empfänger; siehe [SBUS-Anschlussblatt](../connectors/ES02-SBUS-connect.pdf). |
| `H5`, `H6` | 1 SDA, 2 SCL, 3 GND, 4 +3,3 V | AS5600 A/B; zusätzliche GND-Pads 5/6 erscheinen in der Footprint-Netzliste. |
| `H7`, `H8` | 1 U, 2 V, 3 W | Dreiphasige Motoranschlüsse A/B. |
| `H9` | 1 Servo 1, 2 Servo 2, 3/4 gemeinsame Servo-Versorgung, 5/6 GND | Beinservos 1/2. |
| `H10` | 1 Servo 3, 2 Servo 4, 3/4 gemeinsame Servo-Versorgung, 5/6 GND | Beinservos 3/4. |
| `H11` | 1 +5 V, 2 Servo-Versorgung, 3 VIN | Auswahl der Servo-Versorgung; tatsächliche Brücke vor Betrieb ansehen. |
| `CN3` | 1–4 Servo 1–4, 5–7 GND | Signale/GND, keine Servo-Versorgung auf diesen Pins. |
| `H12` | 1 +5 V, 2 GND, 3 SCLK, 4 MOSI, 5 MISO, 6 CS1, 7 unbelegt, 8 GND | Zusätzlicher SPI-Header; seine +5 V nicht mit 3,3-V-Logikpegeln gleichsetzen. |

## Serielle Schnittstellen

**Natives USB CDC ist über den vorhandenen USB-C-Anschluss ohne Hardwareänderung nicht möglich.** Laut PCB-Netzliste verbinden `D+` und `D−` den Anschluss `USB1` mit CH340X `U3`. Die nativen USB-Pins des ESP32-S3, GPIO20 für D+ und GPIO19 für D−, liegen dagegen auf `TX1` und `RX1` für Touch-UART. Natives USB würde eine separate Verbindung zu diesen Pins und die Auflösung des Touch-UART-Konflikts erfordern. Die Firmwareoption „USB CDC On Boot“ ändert diese Verdrahtung nicht. Quellen: [PCB-Netzliste](netlist.md), [Espressif USB-Anschlussbelegung](https://docs.espressif.com/projects/esp-idf/en/stable/esp32s3/api-guides/usb-serial-jtag-console.html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) und [Beobachtungen am vorhandenen Board](../../software/development/usb-serial-flashing.md).

| Pfad | Steck-/Netzseite | Firmware und Einschränkung |
| --- | --- | --- |
| USB/Debug | USB-C `USB1` → CH340X `U3` → `RX0/TX0`; `H1`: 1 +5 V, 2 GND, 3 RX0, 4 TX0 | Flash/`Serial`; am vorhandenen Board als CH340 `/dev/ttyUSB*` beobachtet. Normalmodus 2 Mbaud, Sensordiagnose 115200 Baud. [USB/serial guide](../../software/development/usb-serial-flashing.md) vor Änderungen lesen. |
| Touch / UART1 | `H2`: 1 +5 V, 2 GND, 3 RX1, 4 TX1; `CN4`: 2 +5 V, 3 GND, 4 RX1, 5 TX1 (1/7 GND) | **PCB-Netznamen:** RX1 an GPIO19, TX1 an GPIO20. **Firmware:** `RXD1=20`, `TXD1=19` – gegenläufig zu den Netznamen. Die Zweirad-Firmware liest die externe Touch-TTL-Platine mit 115200 Baud. Der frühere Vierbein-Master/Slave-Modus wurde am 01.10.2026 entfernt; UART1 bleibt für Touch verfügbar. Vor Verdrahtung physische Leitungsrichtung prüfen. |
| SBUS / UART2 | `H3`: 1 +5 V, 2 GND, 3 RX2, 4 TX2; `H4`: 1 GND, 2 +5 V, 3 SBUS über `Q1` | `RX2/TX2` = GPIO1/2. `FUTABA_SBUS` startet UART2 mit 100000 Baud; der Transistor invertiert den SBUS-Eingang für `RX2`. |

`H1/H2/H3` besitzen laut PCB-Footprint zusätzliche GND-Pads 5/6, aber vier Kabeladern. Bei externen Kabeln die Kontakte 1–4 und die Platinenbeschriftung verwenden. Die BOM nennt drei SH1.0-Kabel mit 200 mm (zwei Encoder, Verbindung zweier Einheiten) und eines mit 100 mm (Touch); für den SBUS-Empfänger ein dreipoliges Kabel.

## Externe Geräte, Modi und Datenqualität

- Die RC-Bedienung ist im [README](../../../../README.md) beschrieben: CH5 Stop/Start/Touch, CH6 Haltung/„Mark“, CH7 Roll manuell/auto, CH8 Standard/Pitch/Ball-Balance, CH9/10 Ballkoordinaten. Diese Zuordnung ist Firmware-/Fernsteuerungs-Konfiguration, keine Eigenschaft des Steckers.
- `SENSOR_DIAGNOSTIC_MODE=1` setzt GPIO16/37 zunächst LOW, überspringt Motor-/Servo-Initialisierung und liefert IMU, Akku-ADC und RC-Zustand als CSV. Für das sichere Diagnoseverfahren und die beobachteten Spannungseinbrüche [sensor diagnostic guide](../../software/diagnostics/sensor-diagnostic-mode.md) lesen.
- Das README enthält ältere oder abweichende Hardware-Angaben (`MPU6050`, anderes Servo-Modell, unklare Touchgröße). Die **PCB-Netzliste** belegt die elektrischen Verbindungen; die **BOM** listet Kaufteile; die **Firmware** belegt gegenwärtig konfigurierte GPIOs und Betriebsarten. Bestückung, Kabelorientierung, Servospannungsbrücke und Spannungen unter Last müssen am realen Board geprüft werden.

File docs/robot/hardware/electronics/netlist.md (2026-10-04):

# Elektronik-Hardware: vollständige logische Bauteil-Netzliste

Diese gezielt durchsuchbare Momentaufnahme ergänzt [Einstieg](../system-overview.md) und [technische Referenz](reference.md). Sie wurde aus den `PAD_NET`-Einträgen der beiden `.epcb` im [EasyEDA-Projekt](../../../../hardware/pcb/ProPrj_NavBot-ES02.epro) abgeleitet. Angegeben sind **Bauteil-Designator, Bauteilwert/Typ, Padnummer und Netz**; wo vorhanden steht der Schaltplansymbol-Pinname in eckigen Klammern. Suche mit `rg "U6|\$1N13944|VIN" docs/robot/hardware/electronics/netlist.md`.

`$1N…` bezeichnet ein unbenanntes, aber elektrisch identisches Netz innerhalb **derselben** Platine. `∅` bezeichnet ein im PCB-Netzlistenexport unverbundenes nummeriertes Pad. Mechanische Board-Geometrie ist ausgelassen; bei mehrfachen Gehäusepads auf einem Netz wird jede eindeutige Padnummer einmal genannt. Die Netzliste beschreibt die **geplante logische Verbindung**, nicht Leiterbahnführung, Schicht, Massefläche, Bauteilplatzierung, Bestückung oder gemessene Funktion. Bei Layout-, SI-/EMV- und Reparaturfragen bleibt der PCB-Editor bzw. die reale Platine maßgeblich.

## MAIN (116 Bauteile)

| Ref | Wert / Typ | Pads → Netze |
| --- | --- | --- |
| `C1` | 100nF | `1=GND, 2=ADC` |
| `C2` | 22uF | `1=GND, 2=VIN` |
| `C3` | 22uF | `1=GND, 2=VIN` |
| `C4` | 100nF | `1=GND, 2=VIN` |
| `C5` | 100nF | `1=$1N2389, 2=$1N2414` |
| `C6` | 22uF | `1=GND, 2=+5V` |
| `C7` | 22uF | `1=GND, 2=+5V` |
| `C8` | 100nF | `1=GND, 2=+5V` |
| `C9` | 10uF | `1=GND, 2=+5V` |
| `C10` | 100nF | `1=GND, 2=+5V` |
| `C11` | 10uF | `1=+3.3V, 2=GND` |
| `C12` | 100nF | `1=+3.3V, 2=GND` |
| `C13` | 1uF | `1=GND, 2=+3.3V` |
| `C14` | 1uF | `1=GND, 2=$1N3674` |
| `C15` | 22uF | `1=+3.3V, 2=GND` |
| `C16` | 100nF | `1=GND, 2=$1N4673` |
| `C17` | 100nF | `1=GND, 2=+3.3V` |
| `C18` | 100nF | `1=$1N10925, 2=U_A` |
| `C19` | 100nF | `1=$1N11051, 2=V_A` |
| `C20` | 100nF | `1=W_A, 2=$1N11092` |
| `C21` | 10uF | `1=$1N11138, 2=GND` |
| `C22` | 10uF | `1=$1N11195, 2=GND` |
| `C23` | 100nF | `1=GND, 2=VIN` |
| `C24` | 100uF | `1=GND, 2=VIN` |
| `C25` | 100nF | `1=$1N14887, 2=U_B` |
| `C26` | 100nF | `1=$1N14892, 2=V_B` |
| `C27` | 100nF | `1=W_B, 2=$1N14893` |
| `C28` | 10uF | `1=$1N14895, 2=GND` |
| `C29` | 10uF | `1=$1N14897, 2=GND` |
| `C30` | 100nF | `1=GND, 2=VIN` |
| `C31` | 100uF | `1=GND, 2=VIN` |
| `C32` | 10uF | `1=GND, 2=+3.3V` |
| `C33` | 100nF | `1=GND, 2=+3.3V` |
| `C34` | 10nF | `1=B-, 2=$1N46033` |
| `C35` | 10nF | `1=B-, 2=$1N46092` |
| `C36` | 100nF | `1=VSTA, 2=GND` |
| `C37` | 100nF | `1=B-, 2=GND` |
| `C38` | 22uF | `1=GND, 2=VIN` |
| `C39` | 22uF | `1=GND, 2=VIN` |
| `CN2` | HX25003-3WAP | `1=B2, 2=B1, 3=B-` |
| `CN3` | WAFER-SH1.0-5PLB | `1=SERVO1, 2=SERVO2, 3=SERVO3, 4=SERVO4, 5=GND, 6=GND, 7=GND` |
| `CN4` | WAFER-SH1.0-5PLB | `1=GND, 2=+5V, 3=GND, 4=RX1, 5=TX1, 6=GND, 7=GND` |
| `D2` | SD103AWS_C181207 | `1[C]=$1N13984, 2[A]=$1N14018` |
| `D3` | SD103AWS_C181207 | `1[C]=$1N14914, 2[A]=$1N14916` |
| `D4` | SS54_C7420369 | `1[A]=GND, 2[K]=$1N2414` |
| `D5` | SS54_C7420369 | `1[A]=VBUS, 2[K]=$1N30381` |
| `H1` | WAFER-SH1.0-4PLB | `1=+5V, 2=GND, 3=RX0, 4=TX0, 5=GND, 6=GND` |
| `H2` | WAFER-SH1.0-4PLB | `1=+5V, 2=GND, 3=RX1, 4=TX1, 5=GND, 6=GND` |
| `H3` | WAFER-SH1.0-4PLB | `1=+5V, 2=GND, 3=RX2, 4=TX2, 5=GND, 6=GND` |
| `H4` | PZ254R-11-03P | `1=GND, 2=+5V, 3=$1N8581` |
| `H5` | 1.0-4PWB | `1=SDA2_A, 2=SCL2_A, 3=GND, 4=+3.3V, 5=GND, 6=GND` |
| `H6` | 1.0-4PWB | `1=SDA2_B, 2=SCL2_B, 3=GND, 4=+3.3V, 5=GND, 6=GND` |
| `H7` | PZ254R-11-03P | `1=U_A, 2=V_A, 3=W_A` |
| `H8` | PZ254R-11-03P | `1=U_B, 2=V_B, 3=W_B` |
| `H9` | PH2.54-07-03PWS | `1=SERVO1, 2=SERVO2, 3=$1N10550, 4=$1N10550, 5=GND, 6=GND` |
| `H10` | PH2.54-07-03PWS | `1=SERVO3, 2=SERVO4, 3=$1N10550, 4=$1N10550, 5=GND, 6=GND` |
| `H11` | PZ254R-11-03P | `1=+5V, 2=$1N10550, 3=VIN` |
| `H12` | HDR-F_2.54_1x8P | `1=+5V, 2=GND, 3=SCLK, 4=MOSI, 5=MISO, 6=CS1, 8=GND, 7=∅` |
| `J1` | 0805短接点 | `1=+5V, 2=$1N30381` |
| `L1` | 10uH | `1=$1N2414, 2=+5V` |
| `LED1` | KT-0603R | `1[K]=GND, 2[A]=$1N3996` |
| `LED2` | LED_0603-B | `1[C]=$1N5206, 2[A]=+3.3V` |
| `LED3` | LED_0603-B | `1[C]=$1N18308, 2[A]=+3.3V` |
| `M1` | 2S_RECHARGE | `1=VBUS, 2=GND, 3=VSTA, 4=GND, 5=B1, 6=B2` |
| `Q1` | SS8050(RANGE:200-350)_C2150 | `1[B]=$1N8578, 2[E]=GND, 3[C]=RX2` |
| `Q2` | WSD3056DN33 | `1[S1]=GND, 2[G1]=$1N42523, 3[S2]=B-, 4[G2]=$1N42515, 5[D2]=$1N31293, 6[D2]=$1N31293, 7[D1]=$1N31293, 8[D1]=$1N31293, 9[D1]=$1N31293, 10[D2]=$1N31293` |
| `R1` | 10kΩ | `1=ADC, 2=VIN` |
| `R2` | 1kΩ | `1=GND, 2=ADC` |
| `R3` | 10kΩ | `1=$1N2260, 2=+5V` |
| `R5` | 4.7kΩ | `1=GND, 2=$1N3025` |
| `R6` | 4.7kΩ | `1=GND, 2=$1N3041` |
| `R7` | 1kΩ | `1=TX0, 2=$1N3733` |
| `R8` | 1kΩ | `1=RX0, 2=$1N3813` |
| `R9` | 3.3kΩ | `1=LED2, 2=$1N5206` |
| `R11` | 3.3kΩ | `1=$1N3996, 2=+3.3V` |
| `R12` | 10kΩ | `1=$1N8581, 2=$1N8578` |
| `R13` | 10kΩ | `1=RX2, 2=+3.3V` |
| `R14` | 3.3kΩ | `1=SDA2_A, 2=+3.3V` |
| `R15` | 3.3kΩ | `1=SCL2_A, 2=+3.3V` |
| `R16` | 3.3kΩ | `1=SDA2_B, 2=+3.3V` |
| `R17` | 3.3kΩ | `1=SCL2_B, 2=+3.3V` |
| `R18` | 10kΩ | `1=BOOT, 2=+3.3V` |
| `R19` | 1kΩ | `1=$1N4673, 2=RST` |
| `R20` | 51kΩ | `1=$1N4673, 2=+3.3V` |
| `R21` | 100kΩ | `1=+3.3V, 2=$1N13948` |
| `R22` | 100kΩ | `1=+3.3V, 2=$1N13944` |
| `R23` | 1kΩ | `1=EN_A, 2=$1N14018` |
| `R24` | 100kΩ | `1=+3.3V, 2=$1N14908` |
| `R25` | 100kΩ | `1=+3.3V, 2=$1N14906` |
| `R26` | 1kΩ | `1=EN_B, 2=$1N14916` |
| `R28` | 10kΩ | `1=GND, 2=INT2` |
| `R29` | 4.7kΩ | `1=CS1, 2=+3.3V` |
| `R30` | 4.7kΩ | `1=SCLK, 2=+3.3V` |
| `R31` | 4.7kΩ | `1=MOSI, 2=+3.3V` |
| `R32` | 3.3kΩ | `1=LED3, 2=$1N18308` |
| `R33` | 200Ω | `1=GND, 2=$1N24341` |
| `R34` | 3kΩ | `1=$1N24341, 2=$1N2260` |
| `R35` | 330Ω | `1=B2, 2=$1N46033` |
| `R36` | 330Ω | `1=B1, 2=$1N46092` |
| `R37` | 2kΩ | `1=GND, 2=CS` |
| `R39` | 100kΩ | `1=MISO, 2=+3.3V` |
| `R40` | 180kΩ | `1=+3.3V, 2=VERSION_ADC` |
| `R42` | 100kΩ | `1=VERSION_ADC, 2=GND` |
| `SW1` | SS-12D11G5R | `1=VIN, 2=B2, 4=GND, 5=GND, 3=∅` |
| `SW2` | TS-1088-AR02016 | `1=RST, 2=GND` |
| `SW3` | TS-1088-AR02016 | `1=BOOT, 2=GND` |
| `SW4` | TS24CA | `1=CS, 2=B-, 3=GND, 4=GND` |
| `U1` | RT8289GSP | `1[BOOT]=$1N2389, 4[FB]=$1N2260, 6=GND, 7[VIN]=VIN, 8[SW]=$1N2414, 9[PAD]=GND, 2=∅, 3=∅, 5=∅` |
| `U2` | XC6210B332MR | `1[VIN]=+5V, 2=GND, 3[CE]=+5V, 5[OUT]=+3.3V, 4=∅` |
| `U3` | CH340X | `1[UD+]=D+, 2[UD-]=D-, 3=GND, 4[RTS#]=RST, 5[CTS#]=BOOT, 6[TNOW/DTR#]=BOOT, 7[VCC]=+3.3V, 8[TXD]=$1N3813, 9[RXD]=$1N3733, 10[V3]=$1N3674` |
| `U4` | ESP32-S3-WROOM-1-N8R8 | `1=GND, 2[3V3]=+3.3V, 3[EN]=$1N4673, 4[IO4]=SDA2_A, 5[IO5]=SCL2_A, 6[IO6]=PWM3_A, 7[IO7]=PWM2_A, 8[IO15]=PWM1_A, 9[IO16]=EN_A, 10[IO17]=ADC, 11[IO18]=VSTA, 12[IO8]=VERSION_ADC, 13[IO19]=RX1, 14[IO20]=TX1, 15[IO3]=SCLK, 17[IO9]=MOSI, 18[IO10]=MISO, 19[IO11]=SERVO1, 20[IO12]=SERVO2, 21[IO13]=CS1, 22[IO14]=SERVO3, 23[IO21]=SERVO4, 27[IO0]=BOOT, 28[IO35]=LED2, 29[IO36]=LED3, 30[IO37]=EN_B, 31[IO38]=PWM3_B, 32[IO39]=PWM2_B, 33[IO40]=PWM1_B, 34[IO41]=SDA2_B, 35[IO42]=SCL2_B, 36[RXD0]=RX0, 37[TXD0]=TX0, 38[IO2]=TX2, 39[IO1]=RX2, 40=GND, 41=GND, 16=∅, 24=∅, 25=∅, 26=∅` |
| `U5` | ICM-42688P-HXY | `1[SDO/SA0]=MISO, 4[INT1]=INT1, 5[VDDIO]=+3.3V, 6[GNDIO]=GND, 7=GND, 8[VDD]=+3.3V, 9[INT2]=INT2, 12[CSB]=CS1, 13[SCX]=SCLK, 14[SDX]=MOSI, 2=∅, 3=∅, 10=∅, 11=∅` |
| `U6` | MP6536DU-LF-Z | `1[SW2]=U_A, 2[SW2]=U_A, 3[VSP]=VIN, 4[VSP]=VIN, 5[VSP]=VIN, 6[SW1]=V_A, 7[SW1]=V_A, 8[LS1]=GND, 9[LS1]=GND, 10[BST1]=$1N11051, 12[PWM1]=PWM1_A, 13[PWM2]=PWM2_A, 14[FAULTB]=$1N13984, 15[SHDNB]=+3.3V, 16[PWM3]=PWM3_A, 17[STBYB]=$1N14018, 18[AGND]=GND, 19[FLT3B]=$1N13948, 20[FLT2B]=$1N13944, 22[PGND]=GND, 23[PGND]=GND, 26[VSP]=VIN, 27[VSP]=VIN, 28[VSP]=VIN, 29[SW3]=W_A, 30[SW3]=W_A, 31[LS3]=GND, 32[LS3]=GND, 33[BST3]=$1N11092, 34[VDR2]=$1N11138, 35[AGND]=GND, 36[AGND]=GND, 37[VDR1]=$1N11195, 38[BST2]=$1N10925, 39[LS2]=GND, 40[LS2]=GND, 41[EP]=GND, 11=∅, 21=∅, 24=∅, 25=∅` |
| `U7` | MP6536DU-LF-Z | `1[SW2]=U_B, 2[SW2]=U_B, 3[VSP]=VIN, 4[VSP]=VIN, 5[VSP]=VIN, 6[SW1]=V_B, 7[SW1]=V_B, 8[LS1]=GND, 9[LS1]=GND, 10[BST1]=$1N14892, 12[PWM1]=PWM1_B, 13[PWM2]=PWM2_B, 14[FAULTB]=$1N14914, 15[SHDNB]=+3.3V, 16[PWM3]=PWM3_B, 17[STBYB]=$1N14916, 18[AGND]=GND, 19[FLT3B]=$1N14908, 20[FLT2B]=$1N14906, 22[PGND]=GND, 23[PGND]=GND, 26[VSP]=VIN, 27[VSP]=VIN, 28[VSP]=VIN, 29[SW3]=W_B, 30[SW3]=W_B, 31[LS3]=GND, 32[LS3]=GND, 33[BST3]=$1N14893, 34[VDR2]=$1N14895, 35[AGND]=GND, 36[AGND]=GND, 37[VDR1]=$1N14897, 38[BST2]=$1N14887, 39[LS2]=GND, 40[LS2]=GND, 41[EP]=GND, 11=∅, 21=∅, 24=∅, 25=∅` |
| `U8` | HY2120-LB | `1[OD]=$1N42515, 2[OC]=$1N42523, 3[CS]=CS, 4[VC]=$1N46092, 5[VDD]=$1N46033, 6[VSS]=B-` |
| `USB1` | TYPE-C 16PIN 2MD(073) | `1=GND, 2[VBUS]=VBUS, 4[CC1]=$1N3041, 5[DN2]=D-, 6[DP1]=D+, 7[DN1]=D-, 8[DP2]=D+, 10[CC2]=$1N3025, 11[VBUS]=VBUS, 12=GND, 13[SHELL]=GND, 14[SHELL]=GND, 3=∅, 9=∅` |

## CODER (8 Bauteile)

| Ref | Wert / Typ | Pads → Netze |
| --- | --- | --- |
| `C1` | 10uF | `1=GND, 2=3.3V` |
| `C2` | 100nF | `1=GND, 2=3.3V` |
| `H1` | 1.0-4PWB | `1=SDA, 2=SCL, 3=GND, 4=3.3V, 5=GND, 6=GND` |
| `R1` | 100kΩ | `1=$1N478, 2=3.3V` |
| `R2` | 1kΩ | `1=GND, 2=$1N587` |
| `R3` | 10kΩ | `1=SCL, 2=3.3V` |
| `R4` | 10kΩ | `1=SDA, 2=3.3V` |
| `U1` | AS5600-ASOM | `1[VDD5V]=3.3V, 2[VDD3V3]=3.3V, 4=GND, 5[PGO]=$1N587, 6[SDA]=SDA, 7[SCL]=SCL, 8[DIR]=$1N478, 3=∅` |

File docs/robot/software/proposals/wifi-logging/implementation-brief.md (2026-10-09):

# Implementation brief: buffered Wi-Fi recording

Prepared 2026-09-28 for **GPT-6 Luna, reasoning high**. This is a self-contained implementation assignment: no conversation history or previous plan is needed. Planning only; no implementation or worktree has been started by writing this document.

Engineering planning status: **clean for the scope below**. Hardware performance remains an acceptance test, not an assumed result. Risk tier: **high**, because adding runtime load can affect a balancing robot. Use `plan-eng-review` before implementation, then `security-review`, `cli-qa`, `review`, and `document-release` as applicable. Read their actual instructions when executing them.

## 1. User requirements and non-goals

The user tunes a Navbot-ES02 from a Linux Mint computer on the home Wi-Fi network. They want regulator/sensor data to diagnose pitch/tilt vibration and driving faults. Implement computer-triggered recordings of **20–40 seconds, default 30 seconds**, capturing every actual balance-control tick. Streaming is explicitly allowed. Data may be lost on robot reboot; measurements need not survive power failure. No USB cable should be required during recording.

Use **binary TCP streaming, a bounded internal-RAM buffer on the robot, and continuous file writing on the computer**. The buffer absorbs short network stalls, not the whole recording. Keep existing RC driving independent of the PC. Logging failures stop logging, never block the control loop or change motor commands.

Hardware confirmed by user: **ESP32-S3-WROOM-1, no external RAM, existing pin assignment correct**. Do not enable PSRAM or change wiring. A contrary N8R8 designation in the design export is not evidence of usable PSRAM.

Out of scope: regulator redesign, changing gains/defaults, motor control from the PC, autonomous driving trials, SD/flash logging, OTA, cloud, AP mode, browser UI, live plotting, compression, IMU FIFO/interrupt redesign, guaranteed fixed-rate 1-kHz sampling, recovery of the same recording after TCP reconnect. Preserve parameter tuning if present; do not implement a second tuning product if absent. Do not flash hardware without a separate instruction.

## 2. Worktree and dependency handling

Source workspace: `/home/niko/Dokumente/Bastelei/roboter/Navbot-ES02`. Read its `AGENTS.md` before any project inspection, then `docs/robot/hardware/system-overview.md`, `docs/robot/software/development/usb-serial-flashing.md`, and `agent_notes/robot/usb-serial.md`. Inspect the relevant current code rather than relying on stale line numbers.

The original checkout has important **uncommitted and untracked changes**. A worktree from HEAD alone loses the current robot behavior. The executor must:

1. Record HEAD, branch and `git status --short`; create a temporary snapshot and hash manifest of the current sources. Confirm originals have not changed while copying. If they have, recapture a coherent snapshot.
2. Create an isolated worktree, e.g. sibling `Navbot-ES02-wifi-logging`, on an unused branch such as `wifi-buffered-logging`. Never overwrite an existing worktree/branch. A managed Codex worktree is also suitable; use its returned path explicitly.
3. Apply tracked working-copy changes, including deletions, using a binary diff against captured HEAD. Copy needed untracked code/docs/tests from the sketch, `scripts/`, `agent_notes/`, `dev_notes/`, `docs/`, and `AGENTS.md`. Exclude builds, logs, caches, images and secret configuration. Preserve existing ignore rules; do not bulk-add everything.
4. Verify hashes, inspect for secrets, and create a **local baseline commit in the worktree**. Do not commit, stash, reset or edit the original checkout. Compare the eventual feature diff against this baseline, not old HEAD.
5. Compile the baseline first and record Arduino core/library versions. If parameter-tuning work has since landed in the selected checkout, include it in the baseline. Do not silently cherry-pick an arbitrary branch or assume another worktree is authoritative.

At plan time this checkout contains no implemented Wi-Fi parameter service. Two supported starting conditions:

- **Service exists at execution time:** reuse its station connection, credentials, authentication, boot/build identity, HTTP server, bounded control queue and parameter lock. Extend those components; do not start competing servers/tasks or rename its public APIs unnecessarily.
- **Service absent:** add only the minimal shared WLAN station, authenticated HTTP recording controls and data socket described here. Keep Serial for changing parameters before recording. Do not implement wireless parameter editing/profile management as a dependency. Isolate the small transport utility so a future parameter service can reuse it.

Explain the chosen path in the implementation report. Missing Wi-Fi code is not a reason to stop the whole assignment.

## 3. Existing code to inspect and preserve

Sketch: `src/ES-02/OllieFOCdrive/OllieFOCdrive.ino`; also inspect `filter.*`, `ICM42688.*`, `FUTABA_SBUS.*`, `ble.*`, `robot.*`, and existing Python capture/analysis scripts.

- `loop()` executes motor FOC and sensor work, then enters the balance-control section when `time_dt >= 0.001`. This is **not a fixed 1-kHz scheduler**. Prior observations around 1.664 ms are historical, not a promise of 600 Hz under new network load.
- `print_data()` K58 currently emits a serial DRIVE row approximately every 50 ms. Its position precedes later controller calculations; do not reuse it as the high-rate snapshot point.
- At the end of the timed control section, after regulator/tumble/servo handling and before `now_us1 = now_us`, take one coherent snapshot. Read existing values only; no extra SPI, I²C, ADC or servo operations for logging.
- `ImuUpdate()` polls an IMU configured for 1-kHz ODR, with software filters and attitude estimation. Timestamp **MCU read completion** for age information without changing filters, reads or ODR. Do not label this as sensor conversion time or proof of fresh samples.
- `AnglePid`/`SpeedPid` etc. are configuration objects; `Angle_Pid`/`Speed_Pid` etc. are runtime states with potentially scaled/effective gains. Record that distinction. `PidParameterTuning==0` can replace configured gains automatically.
- Preserve current `V`/`wheelSpeedFeedbackGain`, `wheelSpeedFeedbackOutput`, `balancePidNeedsPriming`, actual-dt wheel estimation, CH3 scaling, gains and all motor/fall logic. Re-read names if later code moved them.
- A BLE connection currently affects the driving input path. WLAN recording must not set `rp.ble_connected` or impersonate BLE driving. Reuse the tuning build's BLE policy if present; otherwise skip BLE init/task only in the explicitly enabled WLAN build. Default legacy build remains unchanged.

Recording supports the existing **two-wheel master balance path** only. Report unsupported diagnostic-only, slave or four-wheel builds clearly. It must record while CH5 is OFF and while ON; changing CH5 is part of a useful trial. Do not apply parameter-write safety gates to read-only acquisition. Never automatically enable CH5.

## 4. Firmware components and real-time contract

Suggested modules: `TelemetryRecorder.{h,cpp}`, `TelemetryWire.{h,cpp}`, `TelemetryTransport.{h,cpp}` plus minimal main-sketch hooks. Keep pure state/format logic host-testable. Reuse existing naming conventions when sensible.

**Producer:** the control loop owns start/stop transitions, metadata snapshot and sample generation. Each control tick performs at most one fixed-size record copy into an already allocated single-producer/single-consumer buffer. No sockets, JSON, allocation/free, filesystem, CRC scan, waiting on a network lock, or unbounded loops in the producer.

**Consumer:** a separate lower-priority sender task batches records and owns the data socket. Block/yield while idle, never busy-spin. Use correct cross-core synchronization; `volatile` alone is insufficient. Prefer bounded SPSC ownership with acquire/release publication and a tested implementation, or very short metadata-only critical sections. Do not hold a critical section around socket calls or bulk serialization. Preserve existing control-task placement and verify priorities; another core alone does not guarantee isolation from Wi-Fi interrupts or shared memory load.

Target a **64-KiB internal record ring**, 512 records × 128 bytes, allocated once before acquisition, plus a bounded 4-KiB sender staging buffer. Include TCP buffers, task stacks, metadata and control service in the memory budget. If 64 KiB cannot be reserved with operating headroom, report the actual supported capacity; optionally use an explicitly advertised 32-KiB configuration. Do not silently exhaust the heap or allocate repeatedly during a run. Reuse buffers across sessions and free only when both owners have stopped.

At 600 Hz, 128-byte records generate 76.8 kB/s; at 1 kHz, 128 kB/s. Forty seconds produces 3.072 MB or 5.12 MB on the PC. An empty 64-KiB ring covers at most 0.85 s or 0.51 s of no progress. Actual reserve is lower when occupied. Expose capacity and high-water mark. Sender must have spare throughput to drain a backlog.

Batch up to **32 records (4096 bytes)**, or flush a nonempty batch after 20 ms. Nonblocking BSD socket calls with `select`/bounded waits must handle partial `send`, `EAGAIN`/`EWOULDBLOCK`, `EINTR`, close and errors. Retain staging data until fully accepted by the socket; never release and reuse bytes still referenced by a pending send. `send` success means accepted by TCP, not saved by the PC. Check APIs against the installed Arduino core/ESP-IDF, not current online examples alone.

Temporarily suppress existing periodic Serial traces during capture to avoid perturbing timing; restore the previous trace selection afterward. Preserve UART parsing and RC safety. Rate-limit/defer error prints reached in the timed section to counters while recording. Do not add synchronous high-rate debug output. Outside recording, preserve legacy telemetry behavior.

## 5. Fixed record schema v1

One profile initially: `balance_v1`, **128 bytes**. Encode explicitly little-endian; no raw ABI-dependent struct dump. Float format IEEE-754 binary32. C++ size assertions and an independent Python golden fixture must agree.

Header (24 bytes):

| Offset | Type | Meaning |
|---|---|---|
| 0 | u64 | MCU monotonic snapshot time in microseconds |
| 8 | u32 | sample sequence, starts at zero for this recording |
| 12 | u32 | flags defined below |
| 16 | u32 | age in µs since last completed MCU IMU read; UINT32_MAX if unavailable |
| 20 | u32 | actual control start-to-start dt in µs |

Then 26 float32 values, in this exact order (104 bytes):

1. `roll_ok`
2. `BodyPitchingFiltered` (stored variable, not silently sign-inverted into the angle setpoint)
3–5. `attitude.gyrof.x`, `.y`, `.z`
6–7. `MovementSpeed`, `BodyTurn`
8–9. `Motor1_Velocity_f`, `Motor2_Velocity_f`
10–14. `Speed_Pid.error`, `.outP`, `.outI`, `.outD`, `.output`
15–19. `Angle_Pid.error`, `.outP`, `.outI`, `.outD`, `.output`
20. `Yaw_Pid.output`
21. `BodyX`
22–23. `motor1.target`, `motor2.target`
24. `wheelSpeedFeedbackOutput`
25. `Voltage`
26. `wheelSpeedFeedbackGain`

Flags: bits 0–1 = current `pid_gains_mode` (0/1/2); bit 2 = tumble; bit 3 = regulator calculated this tick; bit 4 = RC valid/fresh if reliably available; bit 5 = IMU read timestamp available; bit 6 = numeric fault in expected-valid data; bits 7–8 = `roll_mode`, bits 9–10 = `attitude_mode`, bits 11–12 = `posture_or_mark_mode`; remaining bits zero. Validate current mode enum values fit; if not, change the schema version before implementation rather than truncating values. Track validity with actual branches, not just a guess based on CH5.

When no regulator calculation ran, encode runtime PID fields 10–20 as canonical quiet NaN and clear bit 3, instead of presenting stale values as current. Other fields reflect the actual snapshot. Nonfinite expected-valid values set bit 6, remain visible, and make the quality report flag sensor/controller invalidity; do not silently drop those records or confuse them with transport failure.

Record units and sign conventions in metadata, traced to current calculations. Gyro is filtered rad/s, voltage is the existing battery estimate, motor targets are commands rather than measured currents. Do not assume wheel units or the sign of `BodyPitchingFiltered`; document actual code semantics. No extra unmeasured “voltage minimum” field invented to satisfy old analysis code.

Use `esp_timer_get_time()` or an equivalent monotonic 64-bit device clock for timestamps; avoid rollover-prone 32-bit absolute `micros()`. Arrival time at the PC is not measurement time. Records may have irregular spacing; report actual rate/jitter. Neither µs timestamps nor 1-kHz IMU ODR imply µs accuracy or independent 1-kHz samples.

## 6. Wire framing and saved file

Default data socket TCP port **8766**, one authenticated client. The control API advertises the port. No UDP, compression or custom retransmission protocol. TCP is a byte stream: reads may split or combine headers/payloads arbitrarily.

After authentication (next section), server sends frames with a **32-byte little-endian header**:

| Offset | Field |
|---|---|
| 0 | 4 bytes ASCII `NBL1` |
| 4 | u16 protocol version = 1 |
| 6 | u16 type: 1 META, 2 DATA, 3 END |
| 8 | u64 recording_id |
| 16 | u32 frame_sequence, consecutive starting at 0 |
| 20 | u32 payload_length |
| 24 | u32 record_count (DATA only, otherwise 0) |
| 28 | u32 CRC32 of header bytes 0…27 concatenated with payload |

Use standard CRC-32/ISO-HDLC compatible with Python `zlib.crc32`, check vector `123456789` → `0xcbf43926`. CRC is corruption detection, not authentication. Sender computes it off the control loop. Payload limits: META ≤8192 bytes, DATA 1…32 records with exact `count*128` length, END ≤4096 bytes. Reject all other lengths/types/version/order without unbounded allocation. Receiver must never scan corrupt data for a guessed new frame boundary and call it complete.

META is UTF-8 JSON, one frame after actual start: schema, boot_id, recording_id, t_start_us, requested duration, build identity/source hash, actual relevant build flags, configured gains, effective scaling rules, U/V, filter/ODR/calibration configuration, units/field order, buffer capacity, mode interpretation. Snapshot config in loop once; serialize outside it. Do not include credentials or token. If metadata cannot fit, fail prepare explicitly rather than truncate.

DATA contains the records above. END JSON contains reason (`DURATION`, `USER_STOP`, or failure code), generated/queued/sent record counts, first/last timestamps and sequence, stop timestamp, requested/actual elapsed duration, ring high-water mark, overflow counters, interval statistics and `records_crc32`. This CRC covers all DATA payload bytes in stream order, excluding frame headers/META/END, accumulated by sender. State stats must use clear counter definitions; on success all record counts match.

PC stores the exact binary frames beginning with META in `OUTPUT.nblog.partial`; no network authentication bytes. Only after complete validation and successful file flush/fsync rename to `OUTPUT.nblog`. Explicit user stop may create a transport-complete but shorter file with reason USER_STOP; report it as stopped, not a full-duration run. Failures keep `.partial` and an error summary; truncated headers/payloads are reported with last valid offset and records retained.
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

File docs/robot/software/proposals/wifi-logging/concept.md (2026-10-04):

# Konzept: kabelloses Tuning und gepuffertes WLAN-Logging

Stand: 28.09.2026. Recherche der lokalen Arbeitskopie und Herstellerdokumentation; keine Firmwareänderung, kein Flash und keine Hardwaremessung.

## Entscheidung und Anforderungen

**Empfehlung: WLAN im vorhandenen Heimnetz, kleines Python-Werkzeug auf Linux Mint, binäres TCP-Streaming mit kurzem internem RAM-Puffer.** Der Computer ändert Parameter, startet die Aufnahme und schreibt die Daten fortlaufend in eine lokale Datei. Gewünschte Dauer: einstellbar von 20 bis 40 Sekunden, Standard 30 Sekunden. Der Nutzer hat Streaming ausdrücklich als Alternative zur vollständigen lokalen Aufzeichnung zugelassen. Damit ersetzt dieser Entwurf die bisherige Empfehlung für kurze RAM-Aufnahmen mit anschließendem Download.

Zielnutzer ist der Betreiber beim Regler-Tuning und bei der Fehlersuche, insbesondere Neigungsvibrationen. Erfasst werden zunächst alle tatsächlich berechneten Reglerzyklen mit zugehörigen Eingängen und Ausgaben. Ein Neustart darf Messdaten löschen. Heimnetz genügt; kein Access Point, keine Cloud, keine SD-Karte und keine grafische Oberfläche für die Erstversion nötig. Die RC-Fernsteuerung bleibt für die Fahrt zuständig.

Annahme: Firmwareupdates bleiben zunächst über USB; kabellose Updates wurden nicht ausdrücklich beauftragt. Erstinstallation der neuen Firmware benötigt ebenfalls den vorhandenen Flashweg. Das Dauerziel ist 20–40 Sekunden; Kanalumfang und tatsächliche native Reglerfrequenz werden beim technischen Nachweis festgelegt. Die Dauer ist eine Anforderung, noch kein gemessenes Ergebnis.

**Hardware laut Nutzer bestätigt:** ESP32-S3-WROOM-1 ohne externen RAM; die Pinbelegung ist korrekt. PSRAM entfällt. Offen ist nur noch, wie viel interner RAM nach Initialisierung von Regelung und WLAN zuverlässig für den Recorder reserviert werden kann. Dieser Speicher überbrückt Sendepausen; er muss nicht die gesamte Aufnahme enthalten.

## Was bereits vorhanden ist
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

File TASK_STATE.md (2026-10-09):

# Task state: commit firmware build versions

Goal: keep the versions used by a successful firmware build in a file that can be committed with the source after the user confirms that the robot balances.

## Decisions

- Generate `firmware-build-environment.json` in the repository root after a successful build.
- Record the FQBN, resolved ESP32 core version, and libraries selected by the compiler.
- Keep the file observational. Do not install, download, or enforce dependency versions.
- Do not stage or commit the file from the build script. Git history associates it with source changes when the user commits both after a balance check.
- Preserve the existing motor 2 estimated-current change in the sketch.
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

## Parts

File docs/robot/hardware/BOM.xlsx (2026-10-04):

Category | Component | linkS | Specification | Quantity | Description
Hardware | Flanged Bearing | https://www.amazon.com/XIKE-Bearings-3x6x2-5mm-Pre-Lubricated-Selectric/dp/B0D2KYP9JD | 3×6×2.5 mm | 2 | Rod L2
 | Bearing | https://www.amazon.com/uxcell-6701-2RS-Groove-Bearings-Double/dp/B082PQ8DC2 | 12×18×4 mm | 2 | Wheel Hub
 | Hex Socket Screw | https://www.amazon.com/Fgruh-750PCS-Assortment-Washers-Assorted/dp/B0FGV5FCBN?sp_csd=d2lkZ2V0TmFtZT1zcF9hdGY | M3×6 | 2 | Wheel Hub to Rod L2
 | Hex Socket Screw |  | M3×10 | 8 | Motor to Encoder
 | Hex Socket Screw | https://www.amazon.com/Fgruh-1200PCS-Assortment-Washers-Assorted/dp/B0FGV5K8BT?sp_csd=d2lkZ2V0TmFtZT1zcF9hdGY | M2×8 | 4 | Servo to Servo Arm
 | Hex Socket Screw |  | M2×6 | 6 | Wheel Hub to Motor
 | Hex Locking Screw & Nut | https://detail.tmall.com/item.htm?ali_trackid=318_23a26b5b4c76f7f8a2ef9837f0edb194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 | M2×12 (Set) | 8 | Lower Arm to Upper Arm
 | Hex Socket Self-tapping Screw | https://www.amazon.com/Metric-Tapping-Stainless-Assortment-Drilling/dp/B0D1R21JRR | M3×5 | 6 | Mainboard to Bracket ×4 / Touchscreen to Stand ×2
 | Countersunk Hex Self-tapping Screw |  | M3×6 | 2 | Battery Holder
 | Countersunk Hex Self-tapping Screw |  | M3×10 | 12 | Base to Bracket ×4 / Base to Top Cover ×4 / Top Cover to Touchscreen Stand ×4
 | Countersunk Hex Self-tapping Screw |  | M3×18 | 12 | Rod L5 / Rod L6
 | Hex Socket Self-tapping Screw | https://www.amazon.com/Whitewashed-Self-Tapping-Hexagonal-Self-Drilling-Fasteners/dp/B0F1JYTY33 | M1.7×6 | 8 | Servo Arm to Rod L1
 | Hex Socket Self-tapping Screw | https://www.amazon.com/Whitewashed-Self-Tapping-Hexagonal-Self-Drilling-Fasteners/dp/B0F1JYKM64 | M1.7×10 | 8 | Servo to Base
 | Steel Ball (Diameter) | // | 22 mm | 1 | Used for top ball support
Wires | SH1.0 Cable | jLhkiMjvlWzf20CDxy2JfJ4Jcx6Da1d6_YxCGVCAp2FeKimA2qR2AeveBVZlwNlAqCN59ZZSTGm0iPQm9QxrrhbzW8yj_p5FoFC0xtJEouJcRDbRKffhAhPzKMzW5XBSkb6nk7JZq8_URwwl9zUZRra7onyzfd1nP7ulprgyJr7Y40WYrsKdRTsBeodiVKbwYnfKO1gHhlIl8zZwIQNvCrqvjZLzNFy9HY3i_j13vM2EiAD5jhJBrvSYUlat2Xb1bodeY7x2JP6XTelKuG9nJ0bqOmzMA | 200 mm, reverse connection | 3 | 2 Encoders / Communication between two units
 | SH1.0 Cable |  | 100 mm, reverse connection | 1 | Touchscreen control board to mainboard
 | Dupont Cable | https://www.amazon.com/Kidisoii-Dupont-Connector-Pre-Crimped-3P-30CM/dp/B0CCTXZW3D | 3PIN × 10 cm | 1 | To SUBS receiver
Electronics | Encoder Module | // | AS5600 | 2
 | Mini quadruped mainboard | // |  | 1
 | Resistive Touchscreen | https://item.taobao.com/item.htm?app=chrome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 | 181×139 mm | 1
 | 4-wire Resistive Touchscreen Driver | // | Serial TTL level | 1
 | ICM42688P Module | // |  | 1
 | Tire Rubber | https://www.amazon.com/Shaluoman-Soft-Rubber-Tires-Tyre/dp/B07F8Q4BHJ | 37×22 mm (outer diameter × width) | 2
 | Servo | https://item.taobao.com/item.htm?id=534087183869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 | GX-S7445 | 4
 | Brushless Motor | https://www.amazon.com/Gimbal-Brushless-100-200g-Gopro3-Quadcopter/dp/B0FM8JYT38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 | 2208-90kv | 2
 | 18650 Battery Holder | https://www.amazon.com/DAIERTEK-18650-Battery-Holder-Total/dp/B0BG3YLCFD?sp_csd=d2lkZ2V0TmFtZT1zcF9hdGY | 2S battery holder | 1
 | Radial Magnet | https://www.amazon.com/GXHUANG-6x1-5mm-Decorative-Refrigerator-Projects/dp/B0DHQ7FY14 | 6×1.5 mm | 2
 | Remote + Receiver Set | https://www.amazon.com/Radiolink-T12D-Transmitter-Telemetry-Long-Range/dp/B0DB5JHSS6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 | T12D | 1 | Ten control channels are required.
 | 18650 Battery | https://www.amazon.com/MC-ELIN-Rechargeable-Batteries-Flashlights-Headlamps/dp/B0FSQT6BMF |  | 2
3D Printed Parts | loamcake |  |  | 1 | Top Cover
 | lowercover |  |  | 1 | Base
 | magnetsleeve |  |  | 2 | Magnet Sleeve
 | motherboardbracket |  |  | 1 | Mainboard Bracket
 | pole1 |  |  | 2 | Rod L1
 | pole2 |  |  | 2 | Rod L1
 | pole3 |  |  | 2 | Rod L2
 | pole4 |  |  | 2 | Rod L2
 | pole5 |  |  | 2 | Rod L5 (for two-unit connection)
 | pole6 |  |  | 2 | Rod L6 (for two-unit connection)
 | wheelHub |  |  | 2 | Wheel Hub
 | touchscreenstand |  |  | 1 | Touchscreen Bracket

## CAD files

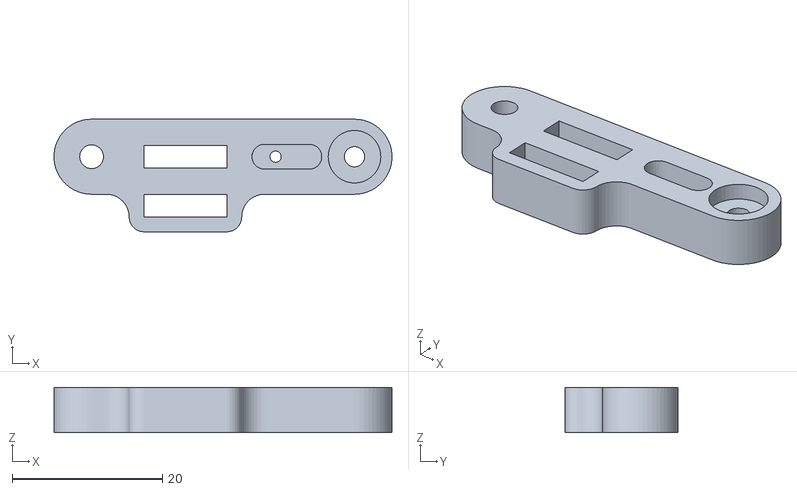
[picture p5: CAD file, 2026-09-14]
hardware/3d print/ThighR.stl
45.0 x 15.0 x 6.00

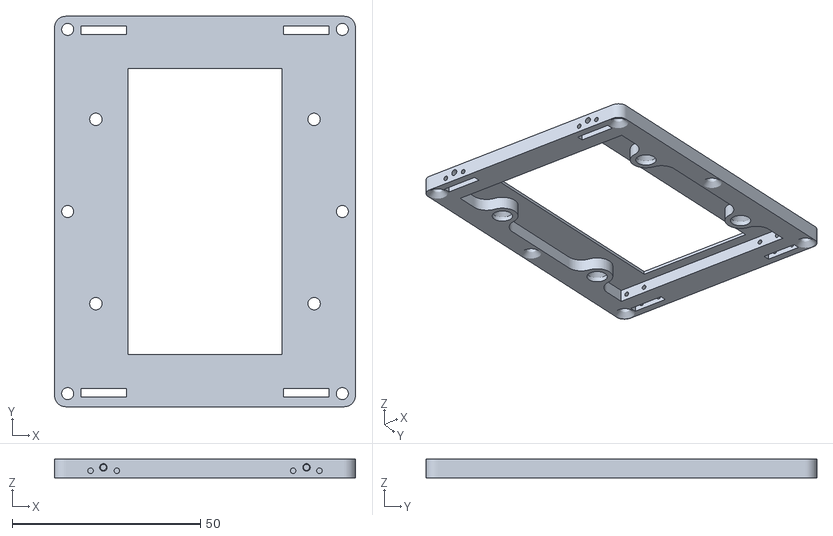
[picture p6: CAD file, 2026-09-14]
hardware/3d print/lowercover.stl
80.0 x 103.8 x 5.00

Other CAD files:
hardware/3d print/ThighL.stl

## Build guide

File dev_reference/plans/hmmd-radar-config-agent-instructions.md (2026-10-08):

# Agent instructions: runtime HMMD radar configuration

## Objective

Add a safe, browser-based way to inspect and change HMMD radar settings while the sensor node is running. Extend the committed sensor channel (`4a8e854`) and keep its browser interface. Do not implement firmware changes, other sensor drivers, or a second transport.

Start by reading the repository `AGENTS.md`, `docs/ros2_pc/software/hmmd-ros2.md` (especially **Sensor-channel interface baseline**), `agent_notes/ros2_pc/sensors/hmmd/README.md`, `agent_notes/ros2_pc/sensors/hmmd/protocol.md`, and `agent_notes/ros2_pc/sensors/hmmd/observations.md`. Before changing serial behavior, also read `agent_notes/robot/usb-serial.md` and `docs/robot/software/development/usb-serial-flashing.md`. Follow the development workflow and create a fresh Scope Contract for this configuration task before implementation. Preserve unrelated worktree files.

## Evidence that defines the starting point

- The HMMD node currently declares `port`, `baud_rate`, `poll_period_sec`, `stale_timeout_sec`, and `diagnostics_period_sec` as read-only ROS parameters. See `src/ros2_pc/ros2/src/hmmd_radar/hmmd_radar/sensor_node.py`.
- `SerialSession` owns the UART and sends a debug-mode initialization byte sequence when opening the port. It currently parses map frames only; it has no request/response command path. See `serial_session.py` and `protocol.py`.
- The production browser manifest exposes map/status receive topics and read-only `/hmmd_sensor/get_parameters`. The generic channel now supports declared ROS services, so hardware configuration should be owned by the HMMD driver and exposed as an explicit service. See `src/ros2_pc/ros2/src/hmmd_radar/web/endpoint-manifest.json` and the interface baseline in the guide.
- The locally saved Waveshare guide says **Maximum Distance Gate** is 0–15, with one gate described as 70 cm, and **Target Disappearance Delay Time** is 0–65535 seconds. These are manufacturer statements, not confirmed measurements on the installed module. The same guide documents a read-configuration command `0x0008`; the local protocol note explicitly says the complete initialization sequence and ACK behavior are unconfirmed. The available guide text does not establish a write command, parameter IDs for these settings, persistence behavior, or read-back semantics.
- In the published map, `range_gates` is a dimension of 16 and a `range_gate` index is 0–15. Do not assume that the UI's array index, the manufacturer's “Maximum Distance Gate” value, and a physical distance are interchangeable. Their mapping, inclusive/exclusive behavior, and effect on the matrix need evidence.

Sources: `agent_notes/ros2_pc/sensors/hmmd/vendor/HMMD-waveshare-wiki.txt`, `agent_notes/ros2_pc/sensors/hmmd/protocol.md`, and the current driver files. Keep manufacturer claims, code behavior, user reports, and physical measurements distinct.

## Evidence gate: establish writable device behavior

Before adding a serial write path, determine from authoritative protocol material and, if available, a controlled device observation:

1. The exact module and firmware revision.
2. The command frame for each supported read and write, including command ID, parameter ID, byte order, value width, units, bounds, and checksums or framing rules.
3. Positive and negative acknowledgement formats, request correlation, timeout behavior, and whether the device echoes or supports reading back the applied setting.
4. Whether a setting applies immediately, needs a mode transition or restart, and persists across power cycles.
5. How command replies interleave with the continuous debug data stream and how to recover from a partial reply or timeout.

Do not infer a write opcode from `0x0008` (documented as read), reverse engineer a command by sending guesses, or report a setting as applied based only on rosbridge submission. If the write protocol cannot be verified, stop short of an enabled hardware write UI: finish the read-only discovery if useful, record the exact missing evidence, and return a small next-step request. A manufacturer GUI screenshot alone does not prove command bytes or ACK semantics.

For any direct serial observation, check `list_ports` through the serial MCP first, establish which process owns the UART, and do not start a second `hmmd_sensor` on the same device. Keep such observations read-only unless the user has approved the specific hardware write and its test value. Record new findings in `agent_notes/ros2_pc/sensors/hmmd/observations.md` with date, evidence, source type, and practical consequence; update `protocol.md` only with supported protocol facts. Do not flash firmware.

## Implementation boundaries

- Keep one serial owner. `SerialSession` should serialize requests with frame polling; no browser, ROS callback, or second node may write directly to the UART.
- Keep transport mechanics generic in the sensor channel. Put HMMD command encoding, decoding, valid-setting metadata, and hardware acknowledgement handling in the HMMD package/driver.
- Prefer a small typed ROS service contract for get/set operations. Use existing standard ROS parameter services only if the value is truly a runtime ROS parameter and the driver can reject a change without claiming it succeeded. Do not tunnel JSON command strings through `std_msgs/String` or mark startup-only parameters writable to bypass the hardware protocol.
- Register only the exact configuration services in `endpoint-manifest.json`. Keep the generated bridge allowlist, loopback bind, and SSH tunnel. Do not add a generic command topic or automatic endpoint discovery.
- A set response must distinguish at least: request validation failure, device rejection, timeout/no acknowledgement, acknowledged application, and (if available) read-back confirmation. State clearly when the device acknowledges a command but cannot confirm persistence.
- The browser should show the current known value, allowed range/unit, request-in-progress state, and final response/error. Do not optimistically replace the displayed current value before the driver response. Preserve the HMMD map/status and generic topic inspector.
- Keep physical-distance conversion out of the UI until gate-to-distance semantics are confirmed for the installed sensor. Label the setting “maximum distance gate” and the map index as an index if that is all evidence supports.

## Suggested first controls

Treat these as candidates, not confirmed writable controls:

| Candidate | Manufacturer statement in local guide | Required confirmation |
| --- | --- | --- |
| Maximum Distance Gate | Integer 0–15; one gate is described as 70 cm | Exact parameter ID and write command; whether the value denotes an index or count; effect on range-map output; device read-back and persistence. |
| Target Disappearance Delay Time | Integer 0–65535 seconds | Exact parameter ID and write command; whether zero is valid; ACK/read-back and persistence. |

Do not expose any other setting unless its name, units, bounds, command encoding, and effect have equivalent evidence.

## Required tests and documentation

- Unit-test byte encoding/decoding with manufacturer-backed vectors. Cover bounds, endianness, positive/negative ACK, malformed reply, timeout, and unrelated map frames arriving during a transaction.
- Test the serial session with a fake port: exactly one owner, serialized requests, no partial-write success, timeout recovery, reconnect behavior, and continued map parsing.
- Test ROS service outcomes with mocked device responses. An error or missing device ACK must not update the reported applied value or parameter state.
- Extend the synthetic rosbridge fixture and browser check to cover loading current settings, submitting a valid setting, pending state, confirmed result, and every failure state. Fixture commands must remain synthetic and absent from production permissions until implemented.
- Preserve tests for the committed generic channel, HMMD map/status validation, startup allowlists, and no replay of writes after reconnect.
- Update `docs/ros2_pc/software/hmmd-ros2.md` with the actual ROS service contract, fields, ranges, units, ACK/read-back meaning, and limitations. Record hardware evidence separately in `agent_notes/`; do not present vendor values as observed device behavior.

## Completion criteria

The task is complete only when a browser user can read and set each enabled setting through the existing page, the driver reports outcomes based on actual protocol responses, invalid or unsupported values are rejected, failures leave the last confirmed value intact, and tests cover the command and request lifecycles. If the evidence gate fails, deliver the verified investigation and identify the missing protocol evidence instead of shipping an unverified write path.

Before completion, run the repository's applicable tests, inspect the full diff, and obtain a fresh independent scope review. Do not deploy to the ros2_pc or issue a physical configuration write unless the user has authorized that concrete action.

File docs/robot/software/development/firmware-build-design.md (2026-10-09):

# Firmware build command design

## Problem

Humans and agents need one command for compiling the NavBot sketch, with options for other Arduino sketches. Flashing remains a separate host operation through the configured `navbot_flash` MCP tool. The repository does not pin Arduino CLI, board core, or library versions.

## Usage

The default command is `python3 scripts/build_firmware.py`. It compiles `src/ES-02/OllieFOCdrive` for the documented ESP32-S3 FQBN into `build/flash`. Callers can supply `--sketch`, `--fqbn`, and `--output-dir`. Repeated `--build-property` values and `--clean` cover common Arduino CLI build options. To flash, call `navbot_flash` MCP `flash_firmware` with the absolute build directory from the active worktree; check serial MCP ports, close the serial MCP connection, and keep balance disabled with motor outputs safe.

## Shape

Use one Python CLI with a normalized immutable `BuildRequest`:

```python
@dataclass(frozen=True)
class BuildRequest:
    sketch: Path
    fqbn: str
    output_dir: Path
    build_path: Path
    build_properties: tuple[str, ...]
    clean: bool
```

The parser supplies repository defaults and resolves caller paths. It derives the Arduino CLI working path as a hidden sibling of the output directory, or accepts `--build-path`. Boundary validation checks the sketch directory, at least one `.ino` file, Arduino CLI availability, and directory creation. The compiler runner builds an argument list and forwards Arduino CLI's output and exit status. It never uploads.

Keep the default sketch and FQBN in `scripts/firmware_build_config.py` for the builder. The explicit working path keeps compilation inside the repository, where agents can write, instead of relying on a user-level Arduino cache directory. The script does not install or pin toolchain packages.

## Synthesis decision

Candidate 3's single Python CLI is the base. It matches the existing uploader and keeps build, upload, and board detection separate. Candidate 1's checks for an `.ino` sketch and an available compiler are included. Candidate 2's simple override model is retained as named command-line options. Its Make target was rejected because it adds a Make prerequisite and shell validation for one operation.

## Tradeoffs

- The script adds a Python entry point but no Python package dependency.
- The default output is reusable, so Arduino CLI controls the contents after a failed build.
- Toolchain versions remain environment inputs. The command is consistent, but builds are not bit-reproducible until package versions are pinned.

## Implementation reconciliation

The implementation must keep the `BuildRequest` data shape and default command above. Any change to the FQBN or sketch default must apply to both build and upload through the shared config module.

## Open questions and risks

The build command does not check the locally installed core or library versions. Use the observed working versions below as a reference when comparing build environments.

After a successful compile, the Python build command updates [`firmware-build-environment.json`](../../../../firmware-build-environment.json) in the repository root. It records the FQBN, resolved platform version, and libraries found in Arduino CLI's compilation database. Git history associates the record with source changes when you commit both files. Commit it after you confirm that the firmware balances. The build command does not stage or commit files.

## Observed working versions

On 2026-10-09, the user confirmed that balancing worked with a firmware build using these installed versions:

| Component | Version |
| --- | --- |
| ESP32 core (`esp32:esp32`) | 3.3.12 |
| Simple FOC | 2.4.0 |
| ArduinoJson | 7.4.3 |
| Queue (`cppQueue`) | 2.1 |

The source was based on commit `b198590` with a working-tree change that sets motor 2 to estimated-current torque control. These are observed build environment versions, not build constraints. `scripts/build_firmware.py` uses whichever core and libraries are installed in the local Arduino CLI environment.

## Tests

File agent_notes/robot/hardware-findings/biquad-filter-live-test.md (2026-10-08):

# Biquad filter live diagnostic capture

Date: 2026-10-07

## Observation

The ESP32-S3 sensor-diagnostic image ran with the CH340 USB-UART connection at 576000 baud and the diagnostic frame interval set to 10 ms. The robot was confirmed secured by the user. The diagnostic source keeps both motor-driver enable pins low and exits setup before initializing BLE, FOC, servos, or balance control.

A 60000-byte capture contained 250 complete 25-column numeric rows. Every row reported `imu_ok=1`. The 249 timestamp intervals had a 10.000 ms median, a 9.966 ms minimum, and a 10.040 ms maximum. No interval exceeded 15 ms.

For this stationary capture, the filtered gyro-X standard deviation was 0.641 of the unfiltered value. The filtered acceleration-Z standard deviation was 0.733 of the unfiltered value. Raw battery readings ranged from 7.250077 to 7.307390 V; filtered readings ranged from 7.262542 to 7.293375 V.

## Evidence

The CH340 appeared as `/dev/ttyUSB0` with USB VID 1A86 and PID 7523. The serial MCP opened that port at 576000 baud, explicitly set RTS and DTR low, and read the CSV stream. A final 60000-byte read was parsed into complete rows; timing came from column 25, IMU readiness from column 24, and signal statistics from the documented raw and filtered channels.

The diagnostic build was flashed from `/tmp/navbot-filter-live/output`. The flash tool reported verified hashes for the bootloader, partition table, and application. No normal control image was flashed.

## Practical consequence and limits

The measured timestamps confirm that the diagnostic stream sustained the configured 100 Hz interval during this stationary capture, with no observed gap above 15 ms. The lower filtered signal deviations show stationary smoothing. This is not a controlled 20 Hz frequency-response measurement. The normal-mode IMU cadence, behavior under motor load, and the physical cutoff under controlled vibration remain unmeasured.

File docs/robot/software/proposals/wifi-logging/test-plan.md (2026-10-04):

# Test plan: buffered Wi-Fi logging

Planning artifact, 2026-09-28. No tests have run yet. The [implementation brief](implementation-brief.md) contains the complete contract. QA surfaces: firmware/internal, network protocol and Python CLI; no UI.

| Area | Cases | Pass condition |
|---|---|---|
| Baseline | Dirty tracked/untracked sources, absent/present tuning service | Snapshot preserved in isolated worktree; correct integration path |
| C++/Python wire | All 26 fields, endian, u64 timestamps, NaN, CRC known vector, frame CRC vs whole-record CRC | Independent implementations agree on golden bytes and sizes |
| Ring ownership | Wraparound, full, partial consumer progress, reset/cleanup race | No overwrite, torn record, use-after-free or producer wait |
| State | Prepare lease, start before data ready, duplicate start/stop, wrong boot/session, drain/ACK expiry | One session, deterministic bounded transitions |
| Clock | Irregular ticks, deadline crossing, long uptime | Device duration honored; actual sample spacing retained |
| Config | U0, active calibration, network/Serial mutation during prepare/capture | Reject or explicit CONFIG_CHANGED; no deferred writes |
| TCP | Partial send, EAGAIN/EINTR, one-byte reads, combined frames, stall/close | Correct progress, bounded memory, explicit recorder failure |
| Integrity | Gap/duplicate, altered header/payload, oversized lengths, missing END, mismatched counts/CRC | Never complete or rename a corrupt file |
| PC storage | No overwrite, disk full, bad directory, fsync error, CTRL-C, ACK timeout | Useful partial retained; validated file not invalidated solely by lost ACK |
| Auth | Missing token, wrong/expired/reused ticket, unauthenticated slow client | Bounded resources; no data access/start |
| Regression | Legacy feature off, tuning if present, existing analysis tests | Prior command/RC behavior preserved |

Build baseline/feature off/feature on with same installed core and libraries, USB CDC disabled, PSRAM off, dummy secrets only. Run CLI full QA (`--help`, status, capture against bounded fake server, decode good/partial/bad files, all exit codes). Do not substitute Python-model tests for actual C++ encoder/ring tests.

Hardware acceptance after separate upload authorization: repeated 20/30/40-s battery-powered no-USB captures; compare baseline/Wi-Fi idle/streaming tick distribution, max latency, producer time, heap/stack, high-water and watchdog behavior. Zero unexplained gaps for successful runs. Deliberate stalls below/above measured reserve. RC still controls robot; STOP only stops logger. No hardware available means these remain explicitly unexecuted, not that host implementation must stop.

Record commands, versions, results and artifacts. End review with proven capabilities vs untested timing limits. See main brief for full acceptance criteria and downstream skills.

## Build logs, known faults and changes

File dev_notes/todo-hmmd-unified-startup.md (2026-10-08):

Ground: Complete. Existing PC-to-ros2_pc flows, nonmatching deployed checkout and shared ROS/UART ownership checks inspected.
Sketch: Complete. Three Luna designs and one Luna cross-judge; A selected with C’s two-port preflight/forwarding and target validation.
Agree: Complete. No human checkpoint requested.
Implement: Complete. One shared local/SSH CLI; old sensor shell and ROS launch entry removed.
Scrap: N/A. Existing Bash transaction fit both targets without a service-manager rewrite.

Arena: Frame, Fan out, Cross-judge, Pick, Graft and Verify complete. Three Luna candidates, one Luna cross-judge, Gemini timed out with no accepted result.
Throughput: One isolated writer owned the code diff; owner reviewed and proved against the live ros2_pc and PC browser endpoints. Independent code review passed. Final independent scope check pending.

Implementation replay gate: Added SO_REUSEADDR only after actual TIME_WAIT reproduced a port false-positive. The isolated test showed EADDRINUSE for plain bind and a clean managed preflight; full remote invocation also succeeded immediately after Ctrl+C.
Final checks: 12 startup CLI tests passed, 10 package tests passed and 1 ROS integration test skipped without local ROS, browser suite passed, package metadata/Python syntax/Bash syntax/CLI help/reference cleanup/whitespace verified. Real ros2_pc local start, PC SSH reuse, static files, production ROS bridge browser client, fresh 20x16 320-value map, baud mismatch refusal and immediate tunnel restart verified.
Read-only code review OK; no comment flags. Gemini unavailable by timeout. Final independent scope verdict OK.

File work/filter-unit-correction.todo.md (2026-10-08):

# Bug fix playbook

1. Reproduce it yourself on the matching surface via the driver skill (Non-negotiables), even when a debug or instrumentation protocol says to ask the user to reproduce. Ask the user only with a stated, specific reason the control surface cannot reach the target, and only after driving it as far as it goes. If it won't reproduce directly, synthesize the trigger, tighten conditions, or instrument until it fires.
2. Binary-search the cause. Form the candidate hypotheses, then rule them out until one survives. Seed them with `how` over the affected subsystem and the **why** skill for regression history. Each pass, take the split that cuts the most remaining problem space, get runtime evidence, eliminate. When program state is unclear, add instrumentation or logging and read it as the code runs. Don't guess. Drive a long or stubborn hunt with Claude Code's `loop` skill. Confirm the surviving *mechanism* with runtime evidence before the step-3 architect/interrogate fan-out.
3. Plan the fix. If it crosses a function boundary, `architect` first. Delegate implementation to a subagent using your configured bug-fix model (default in poteto-mode's Models section) with a specific scope.
4. Verify on the same surface. The original repro now passes. "Inconclusive" or wrong-surface is not a pass. Flag it.
5. Stage the commits so the failing repro lands before the fix in git history. See the **tdd** skill for the failing-test-first cadence when the bug has a cheap local test path. Skip it when the test would be expensive, integration-heavy, or unclear.
6. Run **Opening a PR**.

# Work record

- Source branch checked: `codex/sensor-data-roadmap`, commit `a9c2131`; existing dirty changes are preserved in its other worktree.
- Dedicated worktree created at `/home/niko/.codex/worktrees/filter-unit-correction/Navbot-ES02` on `codex/filter-unit-correction`.
- Contract and frozen plan recorded in `work/filter-unit-correction.scope.md`.
- Caller/cadence investigation, regression test, firmware builds, independent scope reviews, and no-comments review have run. The review findings were applied under the recorded scope amendment.

# Completion record

- The initial independent scope check returned OK for the frozen plan.
- How exploration covered filter math, all source callers, and actual gates. The formula has existed since the initial project commit; the current branch commit only preserved diagnostic rate precision.
- Architecture selected the existing scalar API with cutoffHz and samplingRateHz. A tagged config type was rejected as wider than the task. A third runner and independent cross-judge could not start after the host returned an agent thread limit error. The Gemini adapter returned no visible JSON, so no Gemini findings are claimed.
- Regression test failed before the fix with gain 0.000075 against 0.707107 +/- 0.030, then passed with gain 0.707107.
- Normal and diagnostic builds succeeded without firmware transfer.
- Independent scope reviews and the no-comments review ran. The scope reviews approved the parameter-name-only declaration update and misleading-comment removals; later reviews found stale process notes, which have been corrected.
- Hardware sample rate and jitter remain unmeasured. The normal IMU call is per main-loop pass; RATE_HZ does not schedule it.
- The touchscreen.h declaration now uses samplingRateHz, matching its definition and the Hz-based filter initializer calls.

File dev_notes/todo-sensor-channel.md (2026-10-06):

# Reusable sensor channel

- [x] 1. `how` over the affected subsystem.
- [x] 2. `architect` for parallel design exploration.
- [x] 3. Write the throughput checkpoint as four todo items.
- [x] 4. Delegate code-writing with a specific scope; owner completed and reviewed the work after the writer hit its usage limit.
- [x] 5. Verify on the matching surface, including synthetic browser publish and service request.
- [x] 6. Commit the coherent feature in the target worktree as `4a8e854`.
- [x] 7. If the design is contested, `interrogate` before shipping. Not needed; independent design review selected the approach.
- [ ] 8. Run **Opening a PR**. No PR requested or created.
- [x] Final independent scope check returned `STATUS: OK`.

Architect phases: Ground, Sketch, Agree, Implement, Scrap.
Arena phases: Frame, Fan out, Cross-judge, Pick, Graft, Verify.

Throughput checkpoint:
- [x] Blocking first steps. Grounding, design candidates and independent cross-judge complete.
- [x] Independent workstreams. One implementation writer; owner verification follows.
- [x] Shared mutable state. Implementation was isolated at `/tmp/navbot-sensor-channel`, then copied into the target HMMD worktree after Git metadata writes were denied.
- [x] Smallest safe decomposition. One worker owns transport, manifest, UI, startup and directly related docs/tests because these share the same endpoint contract.

Implementation and verification are complete in the target worktree. See `handoff-sensor-channel.md` for scope and checks. The next task's agent brief is in `dev_reference/plans/hmmd-radar-config-agent-instructions.md`.

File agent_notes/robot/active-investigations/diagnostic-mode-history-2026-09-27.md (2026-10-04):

# Safe diagnostic mode: board observation, 2026-09-27

## Balance activation observation, 2026-09-27

- The user reported that after the normal firmware was restored and calibration saved, moving RC channel 5 to position 1 made the servos vibrate briefly, then the radio signal indication fell to zero and the motors stopped.
- The serial log printed `Voltage:7.38247` immediately before output ceased. In `RXsbus()`, this line is emitted when the filtered battery estimate is at most 7.4 V; the line that would disable the PID mode is commented out. It is therefore a warning, not a firmware shutdown command.
- Earlier diagnostic captures showed about 7.83 V with the drives inactive. A load-dependent voltage drop, control-loop oscillation, or both remain plausible. The log did not establish the 3.3 V rail voltage or a brownout reset reason. Capture servo commands, motor targets, and the minimum raw battery ADC value together before changing control gains.
- A later `balance-trace.log` captured CH5 changing from 0 to 1 around `time_ms=13792`. Before activation, filtered battery was about 7.76 V, the four servo commands were fixed at 15/14/11/16 degrees with zero 20 ms range, and both motor targets were zero. Within about 21 ms of activation, one complete row reported a minimum raw battery estimate of 5.263 V, servo command ranges of 6–8 degrees, and motor targets near -69/-74. Later complete rows reported minimum raw values down to 4.595 V, filtered voltage down to 6.289 V, servo command ranges up to 43 degrees in 20 ms, and motor targets reaching about +130/+200. Logging ceased about 144 ms after activation. Some serial lines were corrupted at 2,000,000 baud, but the trend appears in multiple complete rows.
- Practical consequence: activation coincides with large, rapidly varying actuator commands and a severe board-measured supply sag. The trace establishes both effects but does not resolve which starts the feedback cascade. Check battery, connectors, and board supply under load before changing gains; a controlled test with CH6 in assembly mode could later separate servo motion from wheel drive if the supply is sound.
- Static control-path review found that CH5 mode 1 selects the no-touch balance gains (`AnglePid.P=66`, `I=222`, `D=1`). `PIDcontroller_posture()` runs after an approximately 1 ms tick and computes an unfiltered derivative from `Angle_Pid.previousError`, initially zero. With the observed pre-activation `roll_ok≈-0.4°`, the first derivative term alone could demand roughly -400 velocity units at a 1 ms step. The SimpleFOC velocity path accepts the target directly, and the trace recorded targets around ±200 although `motor.velocity_limit` is 88. This is a deterministic startup demand and missing bound in the control path; it does not yet prove that these alone cause the shutdown.
- A local, unflashed control change now primes the balance derivative on each CH5 off-to-on transition and clamps both motor velocity targets to their configured `velocity_limit`. Wheel velocity estimation also divides each roughly 1 ms encoder delta by a hard-coded 10 ms; that scaling should be reviewed separately because correcting it changes the loop gain by about 10×.
- The user clarified that the robot was resting on a support with the wheels spinning freely during these traces. Thus the balance loop could not change the chassis attitude through wheel-ground contact. The large sustained motor and servo oscillations in this setup cannot by themselves establish unstable gains for ordinary standing. A refreshed trace on the same support showed the first complete CH5=1 row at `time_ms=13628` with `roll_ok=-0.38°`, motor targets about -248/-248, servo range only 1–2°, and raw battery estimate 7.174 V versus 7.77 V before activation. Later rows show motor target magnitude up to 424 and minimum raw battery estimate down to 4.681 V. The immediate -248 target remains consistent with a derivative kick independent of the missing ground contact; subsequent oscillations may be a consequence of this unsupported test geometry.
- A subsequent `balance-trace.log` was captured with both wheels on the ground. Before CH5 activation, filtered battery was about 7.77 V, servo commands were fixed at 15/14/11/16 degrees, and motor targets were zero. At `time_ms=18160`, the first complete CH5=1 row reported raw minimum 6.973 V and motor targets +75.5/+80.0. Around `time_ms=18201`, raw minimum was 4.805 V; later partially corrupted rows showed roll excursions around -6.7° to +5.5°, motor targets exceeding 400, and filtered voltage falling to about 6.0 V by `time_ms=18361` (raw minimum 4.537 V). Thus free-spinning wheels do not explain the entire failure. Values beyond ±88 show that the local derivative-prime/target-clamp change had not been flashed for this capture. The relative contribution of bad gain/derivative behavior and weak supply remains unresolved; do not tune from the free-wheel trace alone.
- The newest `balance-trace.log` (mtime 14:48) shows the user has since flashed the derivative-prime/target-clamp build: all readable CH5=1 motor targets stay within ±88. Before CH5, battery estimates are about 7.77 V, both motor targets zero, and servo commands fixed. The first active row at `time_ms=17637` is truncated but shows `roll_ok=-0.67°`, motor1 target about -44.5, servo ranges 1° and raw minimum 7.241 V. A pure proportional term of 66 × -0.67° predicts about -44, consistent with successful derivative priming. At `time_ms=17658`, both targets are +88, servo ranges 10–11° and raw minimum 5.559 V. By `time_ms=17879`, raw minimum is 4.499 V, filtered estimate 5.960 V, and logging stops. The guard did not prevent the failure. This does not distinguish excessive closed-loop demand from inadequate battery/connector delivery; the board ADC does not report the 3.3 V rail or reset reason. Avoid another full-power balance attempt until supply under load is checked.
- The user subsequently measured the voltage directly at the battery-pack output with an oscilloscope during balance activation and reports that it also collapses there. This independent measurement rules out a purely board-ADC artifact or a voltage drop confined to the downstream robot connector. The reported result does not yet include the minimum voltage, waveform duration, or a load-current measurement. Remaining possibilities include weak/discharged cells or pack contacts/protection, and excessive robot current draw; the trace alone cannot distinguish them. Avoid further full-power balance starts until those are separated.
- For the next diagnostic step, the user wants to assume hardware functionality because the robot operated two days earlier. The firmware provides an immediate gain comparison: RC CH5 mode 1 and mode 2 both execute `PIDcontroller_posture()`, but mode 1 uses no-touch angle gains P=66, I=222, D=1 and speed P/I=0.3/0.3, whereas mode 2 uses with-touch angle gains P=9, I=222, D=0.11 and speed P/I=0.12/0.12. In mode 1 a -0.67° angle error alone predicts a -44 motor velocity target; D=1 converts a 0.1° per 1 ms error change to another 100 target units, already beyond the ±88 diagnostic clamp. A brief, supported CH5=2 trace with neutral controls can test whether the high mode-1 gains drive the oscillation without another firmware upload. Neither this source comparison nor prior traces proves the exact gain that was present in the firmware that worked two days earlier.
- The user then captured `balance-trace-ch5-2.log`. CH5=2 persisted for about 2.35 s (`time_ms=15325..17672`). An early raw minimum was 5.779 V, then complete later rows had raw minima around 7.0 V and filtered voltage around 7.1 V; servo command ranges were small. However all 32 complete CH5=2 motor rows were saturated at opposite signs (±88), so mode 2 is not verified as stable balance control. On the return transition, the final ~0.34 s of logged rows were CH5=1, with no subsequent mode 0; raw minimum fell to 4.556 V, filtered to 5.760 V, and logging ended. This links the severe sag in this run to the mode-1 segment but does not isolate a single gain, since the two modes differ in speed gains and touch behavior, the initial attitude changed, and the motor angle/yaw contributions were not logged. See [Balance-Fallakte](balance-and-power.md) for the neutral evidence summary.

## Observation and evidence

- The connected USB adapter appeared as `/dev/serial/by-id/usb-1a86_USB_Serial-if00-port0` -> `/dev/ttyUSB0`. An `esptool.py chip_id` probe reported ESP32-S3 revision v0.2. Recheck this before any later upload; port names can change.
- `OllieFOCdrive.ino` currently has `SENSOR_DIAGNOSTIC_MODE=0`. Setting it to `1` runs the earlier sensor-only bring-up: setup holds the two plain SimpleFOC driver enable pins (GPIO 16 and 37) low and returns before servo, driver, FOC, BLE and balance initialization. The active diagnostic loop only reads the IMU, battery ADC and SBUS receiver.
- The first verified upload succeeded, but serial text at 2,000,000 baud contained missing and corrupted fields. After changing only diagnostic Serial to 115200 baud, a verified upload produced 32 complete `DIAG` lines in about seven seconds after a reset.
- A plain `pyserial.Serial(port, baud)` open produced no lines: its asserted RTS held this board in reset. Opening with DTR and RTS set false before `open()` released it and produced a clean boot plus diagnostic stream. `scripts/sensor_monitor.py` implements this. The earlier "no output" observation was caused by serial control lines, not an IMU failure. Opening the port still caused a brief reset in two subsequent captures, so reset-reason investigations require leaving the monitor open.
- A 20-second capture contained 97 complete data lines, one boot at monitor opening, no additional reboot, and receiver frame age at most 9 ms. The last line showed 7.830 V, ADC 820, and `rc_failsafe=0`. Stationary gyro readings remained around +0.019/-0.013/+0.026 rad/s; the uncalibrated attitude estimate drifted over the capture. These values are observations, not a validated balance tuning.
- Observed after filter settling: `imu_ok=1`, battery about 7.86 V, `rc_failsafe=0`, `rc_age_ms=9`, `ch3=992`, `ch5=192`; gyro, acceleration, orientation and temperature were present. The boot line reported `reset_reason=1` after a deliberate RTS reset.

## Practical consequence

Use `scripts/sensor_monitor.py` at 115200 baud and the CH340 port for plain text, or connect SerialPlot directly with DTR and RTS off. The earlier diagnostic image's filtered voltage needed about ten seconds to settle; the current CSV image reports direct ADC voltage immediately. The measurements establish that sensors and receiver can be read while drives are inactive; they do not identify why the robot previously shook or lost power under motor load. A later brownout would show `reset_reason=9`, and a reboot restarts the uptime channel. Check supply wiring and voltage under load before re-enabling motor control.

## SerialPlot update, 2026-09-27

- The diagnostic stream now emits 14 fixed-position numeric CSV columns every 50 ms. README.md lists their names and units. The battery column uses direct ADC conversion to avoid the filtered startup transient.
- Rebuilt for `esp32:esp32:esp32s3:USBMode=hwcdc,CDCOnBoot=default` and uploaded to the re-identified ESP32-S3 at `/dev/ttyUSB0`; every flashed segment passed hash verification.
- A seven-second hardware capture yielded 125 complete numeric rows, each with exactly 14 fields and a 50 ms median timestamp step. First row: raw battery 7.833 V, IMU ready; last row: raw battery 7.833 V, receiver age 3 ms, failsafe 0. Fifteen nonnumeric boot/setup lines preceded the stream, so set SerialPlot to a fixed 14-channel ASCII CSV format and leave DTR and RTS off.
- The user's SerialPlot 0.13.0 log showed `boot:0x21 (DOWNLOAD(USB/UART0))` and `waiting for download` after it opened `ttyUSB0`. This means the chip booted its flash loader, so it cannot emit firmware CSV. The likely trigger is DTR holding the ESP32's boot strap low during a reset; deassert both DTR and RTS in SerialPlot, then pulse RTS or press RESET/EN while DTR remains off. A normal boot reports `SPI_FAST_FLASH_BOOT`. The reported "invalid number of channels" warnings were for ROM boot text, not malformed diagnostic CSV.

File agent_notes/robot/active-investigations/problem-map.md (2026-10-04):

# Fehlersuche Navbot-ES02: getrennte Beobachtungen

Stand: 2026-09-27. Die Kennungen unten bezeichnen **Symptome**, keine bewiesenen unabhängigen Defekte. Sie können zusammenhängen; die bisherigen Daten zeigen nicht, ob sie eine gemeinsame Ursache haben. Für Details und Einschränkungen die jeweilige Fallakte lesen.

| Fall | Beobachtung | Bisherige Evidenz | Eigene offene Frage |
| --- | --- | --- | --- |
| **A: Schwingung im Stand** | Bei älteren CH5-Balanceversuchen starke Bewegung; mit sanften Diagnose-Gains deutlich ruhiger und laut Nutzer selbstständig stabil. Die später bei Yaw-P=10 beobachtete leichte Schwingung war Vor-/Zurückkippen um die Radachse. | [Balance-Fallakte](balance-and-power.md), insbesondere `control-ch5-2*.log` und die dort dokumentierten P=6-/Yaw-Versuche. | Welche Rückführung und welche Gain-Werte erklären die verbleibende Bewegung im Stand? |
| **B: Spannungseinbruch / Ausfall bei Aktivierung** | Bei früheren CH5-Versuchen starke Board-ADC-Einbrüche und endende Aufzeichnungen; Nutzer sah einen Einbruch auch direkt am Akkupack per Oszilloskop. Ein protokollierter früherer Versuch lief nach einem kurzen Einbruch weiter, sodass nicht jedes Spannungsminimum einem Neustart entspricht. | [Balance-Fallakte](balance-and-power.md), `balance-trace*.log`; Oszilloskopbeobachtung nur als Nutzerbericht, ohne Kurve oder Strommessung. | Was verursacht den Pack-Einbruch, und welches Ereignis schaltet Motoren/Empfänger tatsächlich ab? |
| **C: Zunehmendes Kippen beim Fahren** | Im ruhigen Stand laut Nutzer stabil; bei schneller Fahrt über CH3 zunehmend Kippen und Beschleunigen in beide Fahrtrichtungen. Beim Anhalten nach Vorwärtsfahrt rollt er laut Nutzer teils rückwärts und kippt manchmal um. CH8=2 beim schnellen Fahrversuch; Touchscreen nicht angeschlossen. | [Fahr-Fallakte](drive-instability.md). Die erste CH5-aus-Baseline enthält zu viele serielle Beschädigungen, um Bewegungsverhalten auszuwerten; **noch kein verwertbarer Fahr-Trace**. | Welche Größen wachsen beim Fahren oder Nachschwingen: Geschwindigkeitssoll/Fehler, `BodyX`, Neigungssoll, Motorziele oder Versorgungseinbruch? |
| **D: Leichte Richtungsabweichung** | Vorwärts leicht nach rechts; rückwärts häufig geradeaus, aber unsicher. | Nutzerbericht in der [Fahr-Fallakte](drive-instability.md); keine Messreihe. | Reproduzierbar und an CH4/Gierbefehl, Motor-/Radunterschied oder etwas anderes gebunden? |
| **E: Kalibrier-/Servobeobachtung** | `C1` und `C-1` bewegten laut Nutzer den angesprochenen Servo gleichgerichtet; mehrere gespeicherte Nullpunkte erschienen nach Neustart erneut. | Nutzerbericht und Startmeldungen in der [Balance-Fallakte](balance-and-power.md); keine unabhängige Servowinkelmessung. | Ist die Befehlsinterpretation oder Servo-Reaktion reproduzierbar und für A–D relevant? |

## Gemeinsamer Kontext und Grenzen

- Der Roboter lief nach Nutzerangabe etwa zwei Tage vor den Versuchen. Ein Flash der GitHub-Standardfirmware ging der Stand-Schwingung zeitlich voraus. Der frühere Firmwarestand und die damaligen Einstellungen sind unbekannt; eine Firmwareursache ist dadurch nicht bewiesen.
- Die Kalibrierwerte werden laut Code in ESP32-NVS (`Preferences`) gespeichert und einige Werte erschienen nach Neustart wieder. Serielle Live-PID-Gains werden nicht dauerhaft gespeichert. Für alte und neue Traces gelten verschiedene lokale Firmwarestände; deren Zuordnung steht in der Balance-Fallakte.
- Die lokale Arbeitskopie ist verändert und nicht committed. Aktuell ist `DIAGNOSTIC_LIVE_TUNING_DEFAULTS=1`, womit die sanften Werte beim Start geladen werden; ursprüngliche GitHub-Gains und Live-Änderungen dürfen nicht verwechselt werden. Der tatsächlich geflashte Binärstand ist nicht per Hash ausgelesen.
- Ein beobachteter Spannungseinbruch kann Folge hoher Aktuatoranforderung sein oder deren Verhalten beeinflussen. Die bisherigen Daten legen keine allgemeine Reihenfolge oder gemeinsame Ursache für A–E fest.
- Hardwarehinweise und Messgrenzen stehen in [Hardwareübersicht](../../../docs/robot/hardware/system-overview.md), [Sensor-Diagnoseanleitung](../../../docs/robot/software/diagnostics/sensor-diagnostic-mode.md) und [USB/serial notes](../usb-serial.md). Neue Messungen mit eindeutigem Dateinamen und dokumentierten Schalterstellungen aufbewahren.

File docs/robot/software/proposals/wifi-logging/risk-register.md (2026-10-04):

# Risk register: buffered Wi-Fi logging

Planning status **clean** for specified scope; runtime/hardware evidence pending. Risk tier **high**. Required downstream `security-review`, `cli-qa`, `review`, `document-release`. [Main brief](implementation-brief.md) resolves product requirements and implementation defaults; no additional user answers are prerequisites for host implementation.

| Risk / evidence | Impact | Required mitigation |
|---|---|---|
| Dirty checkout; tuning plan exists but code absent | Lost current controls or duplicated service | Snapshot baseline; inspect and select explicit reuse/minimal-transport path |
| Synchronous sender or unbounded locks | Balance timing disturbed | No network/alloc/format in producer, bounded SPSC ownership, stalled-sender test |
| Ring index/data races across cores | Silent corrupt records | Correct publication/ownership, wrap/race tests, CRC and sequences |
| Sending faster than link/receiver | Growing heap or lost samples | Fixed capacity, high-water reporting, explicit BUFFER_FULL, no rate reduction |
| Socket accepts data before PC saves it | False success | END verification, fsync/rename, separate application ACK status |
| Reconnect lacks already-sent samples | Fabricated complete run | No replay promise, fail same session, partial file retained |
| Clock/snapshot mismatch | Wrong vibration inference | MCU monotonic timestamps, end-of-control snapshot, actual dt/IMU-read-age semantics |
| Inactive controller fields stale | False PID diagnosis | Explicit validity flag and NaN runtime fields |
| Auto or serial gains change mid-run | Misleading “constant configuration” result | Manual mode requirement, mutation gate, change detector before sample |
| Existing traces/error prints/flash writes | Hidden timing perturbation | Session trace suppression and counters; calibration gate; restore afterward |
| Wi-Fi service or BLE affects RC | Unexpected motion/input source | Independent session control, feature-specific BLE policy, no motor commands |
| Oversized frames/auth abuse | Memory exhaustion or data exposure | Length caps before allocation, finite leases, one client, token/ticket checks |
| Credentials committed/logged | Unauthorized home-network access | Ignored local secrets, nonsecret fixtures, no token CLI/URL/debug |
| HTTP/TCP unencrypted | Network observer can see traffic | Explicit trusted-home-network scope, no claims of TLS confidentiality |
| Nominal kHz mistaken for real sample rate | Invalid spectral conclusions | Native tick rate only, measured timing, no FIFO/FFT claims in v1 |
| Hardware test unavailable | Unsupported performance claims | Finish host/build work; mark all physical acceptance unexecuted |

Failure handling must leave existing driving/fall logic unchanged, free resources deterministically, and report incomplete measurements honestly. No automatic flash, driving trial or safety-limit adjustment is authorized by this plan.

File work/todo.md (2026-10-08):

### Merge task checkpoint

- **Blocking first steps:** inspect both branch histories, the frozen source scope, target logger, output formats, and capture consumers before resolving the logger conflict.
- **Independent workstreams:** read-only source/target exploration and architecture candidates ran independently; implementation and harness updates were sequenced because they share the logger record API.
- **Shared mutable state:** one target `SerialLogger` queue and one sender own the asynchronous log stream. The separate source `Telemetry` sender was not retained.
- **Smallest safe decomposition:** port only selected snapshots and bounded failure behavior into the target logger; preserve the target schemas and existing cadence.

### Verification

- [x] Host blocked-sender test, including capacity 32, FIFO, reuse, and sticky overflow.
- [x] Normal firmware build.
- [x] Diagnostic firmware build with default macro restored.
- [ ] Independent scope gate, final diff check, merge commit.

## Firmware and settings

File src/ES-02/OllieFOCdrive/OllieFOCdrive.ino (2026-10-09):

#include <Arduino.h>
#include <esp_system.h>
#include <esp_timer.h>
#include <SimpleFOC.h>
#include "FUTABA_SBUS.h"
#include "ServoControl.h"
#include "ICM42688.h"
#include "MahonyFilter.h"
#include "OllieFOCdrive.h"
#include "filter.h"
#include "touchscreen.h"
#include "ble.h"
#include "robot.h"
#include "Logging.h"
#include "RobotLogCapture.h"
#include "LegKinematics.h"
#include "Calibration.h"
#include "CalibrationStore.h"

class LoggingCommandStream : public Stream {
 public:
  int available() override { return Serial.available(); }
  int read() override { return Serial.read(); }
  int peek() override { return Serial.peek(); }
  size_t write(uint8_t value) override {
    if (Logging::profile() != Logging::Profile::Idle) return 1;
    return Serial.write(value);
  }
  size_t write(const uint8_t *buffer, size_t size) override {
    if (Logging::profile() != Logging::Profile::Idle) return size;
    return Serial.write(buffer, size);
  }
  void flush() override {
    if (Logging::profile() == Logging::Profile::Idle) Serial.flush();
  }
};

LoggingCommandStream commandStream;
Commander command = Commander(commandStream);
Calibration calibration;
CalibrationStore calibrationStore;

// ----- Editable Constants
#define Communication_object COMMUNICATION_OBJECT_TWO_WHEEL_BALANCE          // 0: two-wheel balance  1: simpleFOC Studio host computer  2: control dual motors

// Safe bring-up: read sensors and receiver without energizing wheels or servos.
// Set to 0 only after the diagnostic readings and power supply are checked.
#define SENSOR_DIAGNOSTIC_MODE 0

// Tuned two-wheel drive defaults, including corrected wheel-speed timing and
// CH3 scaling. Apply them at startup and through a CH5 switch transition.
// Set to 0 to restore the repository's mode-dependent defaults.
#define DIAGNOSTIC_LIVE_TUNING_DEFAULTS 1

#define AdjusParameter ADJUST_BALANCE_SPEED_YAW_ROLL        // 0: balance, speed, yaw, roll parameter tuning   1: ball pushing

//      Two-Wheel PID Gains for Remote Control Mode (Without Touchscreen)
#define PID_ROLL_P_NO_TOUCH 0.06
#define PID_ROLL_I_NO_TOUCH 0.0
#define PID_ROLL_D_NO_TOUCH 0.0
#define PID_ROLL_LIMIT_NO_TOUCH 2
#define PID_SPEED_P_NO_TOUCH 0.045
#define PID_SPEED_I_NO_TOUCH 0.005
#define PID_SPEED_D_NO_TOUCH 0
#define PID_SPEED_LIMIT_NO_TOUCH 50
#define PID_ANGLE_P_NO_TOUCH 5
#define PID_ANGLE_I_NO_TOUCH 200
#define PID_ANGLE_D_NO_TOUCH 0.11
#define PID_ANGLE_LIMIT_NO_TOUCH 0.1

//      Two-Wheel PID Gains for Remote Control Mode (With Touchscreen)
#define PID_ROLL_P_WITH_TOUCH 0.08
#define PID_ROLL_I_WITH_TOUCH 1.5
#define PID_ROLL_D_WITH_TOUCH 0.005
#define PID_ROLL_LIMIT_WITH_TOUCH 2
#define PID_SPEED_P_WITH_TOUCH 0.045
#define PID_SPEED_I_WITH_TOUCH 0.005
#define PID_SPEED_D_WITH_TOUCH 0
#define PID_SPEED_LIMIT_WITH_TOUCH 50
#define PID_ANGLE_P_WITH_TOUCH 5
#define PID_ANGLE_I_WITH_TOUCH 200
#define PID_ANGLE_D_WITH_TOUCH 0.11
#define PID_ANGLE_LIMIT_WITH_TOUCH 0.1

#define IMU_SAMPLING_RATE_HZ 1000.0f  // Sampling frequency
#define IMU_LPF_CUTOFF_FREQ_HZ 50.0f  // See docs/robot/ROBOT_ROADMAP.md
#define BOARD_PIN_LED 35        // LED IO
#define BOARD_PIN_BATTERY_VOLTAGE_ADC 17  // Battery voltage IO

#define IMU_ACCEL_RANGE_G 8.0              // Unit: g
#define IMU_GYRO_RANGE_DEG_PER_SEC 2000.0  // Unit: °/s

// GPIOs for the four leg-servo signals, in ServoControl order.
#define LEG_SERVO_1_SIGNAL_PIN 11
#define LEG_SERVO_2_SIGNAL_PIN 12
#define LEG_SERVO_3_SIGNAL_PIN 21
#define LEG_SERVO_4_SIGNAL_PIN 14

#define SBUS_CHANNEL_MAX 1792
#define SBUS_CHANNEL_MIN 192

#define SERIAL_BAUD_RATE 576000
#define DIAGNOSTIC_SERIAL_BAUD_RATE 576000
#define LIVE_TUNING_SERIAL_BAUD_RATE 576000
#define DIAGNOSTIC_LOG_INTERVAL_US 10000 // Diagnostic CSV rows are emitted at 100 Hz.
constexpr unsigned int DIAGNOSTIC_LOG_SAMPLE_RATE_HZ = 1000000U / DIAGNOSTIC_LOG_INTERVAL_US;
// Conservative drive tuning parameters; verify the wheel feedback sign on hardware.
constexpr float DRIVE_BODY_X_LIMIT_M = 0.010f;
constexpr float DRIVE_WHEEL_FEEDBACK_LIMIT = 8.0f;
constexpr float DRIVE_TILT_REDUCTION_START_DEG = 5.0f; // TODO where used?
constexpr float DRIVE_TILT_REDUCTION_FULL_DEG = 10.0f;
// -------------------------------------

constexpr float BODY_HEIGHT_OVERRIDE_DISABLED_M = 0.0f;
constexpr float BODY_HEIGHT_MIN_M = 0.05f;
constexpr float BODY_HEIGHT_DEFAULT_M = 0.06f;
constexpr float BALL_POISE_MAX_BODY_HEIGHT_M = 0.07f;
constexpr float BODY_HEIGHT_MAX_M = 0.09f;
constexpr int BODY_HEIGHT_COMMAND_FILTER_INDEX = 2;

// Body
float TargetBodyHeightOverrideM = BODY_HEIGHT_OVERRIDE_DISABLED_M;  // Zero disables the Commander height override.
float BodyHeightCommandM = BODY_HEIGHT_DEFAULT_M;  // Remote-controlled body height
float BarycenterX = 0;              // Center of mass X
float BodyPitching = 0;             // Pitch
float BodyRoll = 0;                 // Roll
float MovementSpeed = 0;            // Movement speed
float BodyTurn = 0;                 // Turning
float SlideStep = 0;                // Slide step
float BodyX = 0;                    // X position (controller output)
int RobotTumble = ROBOT_NOT_TUMBLING;  // Fall-detection state, see docs/robot/ROBOT_ROADMAP.md


// 滤波
float BodyHeightCommandFilteredM = BODY_HEIGHT_DEFAULT_M;
float BodyPitchingFiltered = 0;      // Pitch
float BodyRollFiltered = 0;          // Roll
float SlideStepFiltered = 0;         // Slide step
biquadFilter_t BodyCommandFilterLPF[12];  // Second-order low-pass filter
float TouchYPidOutputFiltered = 0;
float TouchXPidOutputFiltered = 0;

float bodyCommandFilterCutoffHz = 200; // Low-pass cutoff frequency (Hz) for remote-control body command filtering.
float bodyCommandFilteringEnabled = 1;

void SetBodyCommandFilterCutoffHz(char *cmd) {
  command.scalar(&bodyCommandFilterCutoffHz, cmd);
}

void SetBodyCommandFilteringEnabled(char *cmd) {
  command.scalar(&bodyCommandFilteringEnabled, cmd);
}

int statusLedOn = 1;
int statusLedTicks = 0;
int statusLedPeriodTicks = 100;
// Battery Voltage Measurement
biquadFilter_t VoltageFilterLPF;  // Second-order low-pass filter
uint16_t VoltageADC = 0;          // Battery voltage ADC data
uint16_t VoltageADCMin = 0;       // Lowest raw battery reading since the last balance trace row
float VoltageADCf = 0;            // Battery voltage ADC data
float Voltage = 0;                // Battery voltage

// IMU
//  Create MahonyFilter object, set proportional gain and integral gain
MahonyFilter mahonyFilter(0.4f, 0.001f);
// Accelerometer range (here set to ±8g)
// Gyroscope range (here assumed to be ±2000°/s)
attitude_t attitude;
float rollBiasCorrected;
float pitchBiasCorrected;

zeroBias_t zeroBias;  // Zero offset TODO of what?
unsigned long timestamp_prev = 0;
uint32_t controlGateSequence = 0;
uint32_t activeTraceSequence = 0;
uint32_t diagnosticSequence = 0;
float IMUtime_dt = 0;

/* Low-pass filter parameters TODO Imu? */
float prevImuSampleRateHz = IMU_SAMPLING_RATE_HZ;            // Sampling frequency
float prevImuLowPassCutoffHz = IMU_LPF_CUTOFF_FREQ_HZ;  // Cutoff frequency

float imuSampleRateHz = IMU_SAMPLING_RATE_HZ;            // Sampling frequency
float imuLowPassCutoffHz = IMU_LPF_CUTOFF_FREQ_HZ;  // Cutoff frequency
biquadFilter_t ImuFilterLPF[6];                  // Second-order low-pass filter

void setImuSampleRate(char *cmd) {
  command.scalar(&imuSampleRateHz, cmd);
}
void setImuLowPassCutoff(char *cmd) {
  command.scalar(&imuLowPassCutoffHz, cmd);
}

void Target_Body_Height(char *cmd) {
  command.scalar(&TargetBodyHeightOverrideM, cmd);
}

// Complementary filter TODO filter for what?
float angleGyroX, angleGyroY, angleGyroZ,
  angleAccX, angleAccY;
float angleX, angleY, angleZ;
float accCoef = 0.02f;
float gyroCoef = 0.98f;

// Servo zero position offsets
void zeroBias_servo1(char *cmd) {
  command.scalar(&zeroBias.servo1, cmd);
}
void zeroBias_servo2(char *cmd) {
  command.scalar(&zeroBias.servo2, cmd);
}
void zeroBias_servo3(char *cmd) {
  command.scalar(&zeroBias.servo3, cmd);
}
void zeroBias_servo4(char *cmd) {
  command.scalar(&zeroBias.servo4, cmd);
}

bool pid_gains_mode_is_enabled(int mode) {
  return (mode == REMOTE_CONTROL_PID_GAINS_MODE_ON_WITHOUT_TOUCH || mode == REMOTE_CONTROL_PID_GAINS_MODE_ON_WITH_TOUCH);
}

//  Create ServoControl object
ServoControl servoControl(LEG_SERVO_1_SIGNAL_PIN, LEG_SERVO_2_SIGNAL_PIN,
                          LEG_SERVO_3_SIGNAL_PIN, LEG_SERVO_4_SIGNAL_PIN);
int servoTraceAngle[4] = { 0, 0, 0, 0 };  // Last angle arguments sent to the four servos

// Remote control
FUTABA_SBUS sBus;
int sbusFrameIntervalMs = 0;
int pid_gains_mode = REMOTE_CONTROL_PID_GAINS_MODE_OFF;
int posture_or_mark_mode = REMOTE_CONTROL_PM_POSTURE_MODE;
int roll_mode = REMOTE_CONTROL_ROLL_MODE_MANUAL;
int attitude_mode = REMOTE_CONTROL_ATTITUDE_MODE_DEFAULT;
float top_ball_x = 0;
float top_ball_y = 0;
float sbus_top_ball_x_smoothed = 0;
float sbus_top_ball_y_smoothed = 0;

//  Create PID controller instance
float Select = 0;             // Select the data to print //TODO where is this used? needed?
float CalibrationSelect = 0;  // Save calibration data 0: Calibration end  1: Calibrate gyroscope  2: Calibrate Euler angle  3: Calibrate servo

float PidParameterTuning = DIAGNOSTIC_LIVE_TUNING_DEFAULTS ? 1 : 0;  // 0: auto gains  1: live tuning

// TODO where do these values come from?  why 2 pid controllers?
PIDController AnglePid(5, 200, 0.11, 0, 0.1);
PIDController SpeedPid(0.045, 0.005, 0, 0, 50);
PIDController YawPid(4, 0, 0, 0, 0);
PIDController RollPid(0.06, 1.5, 0.003, 0, 2);  //
PIDController TouchXPid(0.2, 0, 0.04, 0, 0);    //
PIDController TouchYPid(0.2, 0, 0.08, 0, 0);    //

float control_torque_compensation = 0;  // Control torque compensation
float wheelSpeedFeedbackGain = 0.0f;
float wheelVelocityFeedbackCorrection = 0;
float driveTiltReductionGain = 1.0f; //TODO what does it do?
float driveEffectiveSpeed = 0;
float driveSpeedBodyXRaw = 0;

float pidTimestepSec = 0.01;

//  Create MyPIDController instance, set initial parameters TODO why 2 pid controllers? the pid controller names are the same for both modes, which is confusing.
MyPIDController Angle_Pid(0, 0, 0, 0, 0, pidTimestepSec, 0, 0);  // p i d iLimit outputLimit dt EnableDFilter cutoffFreq
MyPIDController Speed_Pid(0, 0, 0, 0, 0, pidTimestepSec, 0, 0);
MyPIDController Yaw_Pid(0, 0, 0, 0, 0, pidTimestepSec, 0, 0);
MyPIDController Roll_Pid(0, 0, 0, 0, 0, pidTimestepSec, 0, 0);

MyPIDController TouchX_Pid(0, 0, 0, 0, 10, pidTimestepSec, 0, 0);
MyPIDController TouchY_Pid(0, 0, 0, 0, 8, pidTimestepSec, 0, 0);
bool balancePidNeedsPriming = true; // what does this mean? 

void ControlTorqueCompensation(char *cmd) {
  command.scalar(&control_torque_compensation, cmd);
}

void CbWheelSpeedFeedbackGain(char *cmd) {
  command.scalar(&wheelSpeedFeedbackGain, cmd);
}

void CbDriveTiltReductionGain(char *cmd) {
  command.scalar(&driveTiltReductionGain, cmd);
}

void Pid_Parameter_Tuning(char *cmd) {
  command.scalar(&PidParameterTuning, cmd);
}
void User_command(char *cmd) {
  if (*cmd == '{') {
    rp.json_test(cmd);
  }else{
    Pid_Parameter_Tuning(cmd);
  }
}

void TwoKp(char *cmd) {
  command.scalar(&mahonyFilter.twoKp, cmd);
}
void TwoKi(char *cmd) {
  command.scalar(&mahonyFilter.twoKi, cmd);
}

void KeyScalar(char *cmd) {
  command.scalar(&Select, cmd);
  RobotLogCapture::setProfileForSelector(static_cast<int>(Select));
}
void KeyCalibration(char *cmd) {
  command.scalar(&CalibrationSelect, cmd);
}

#if AdjusParameter == ADJUST_BALANCE_SPEED_YAW_ROLL
void CbAnglePid(char *cmd) { //TODO cb meaning?
  command.pid(&AnglePid, cmd);
}
void CbSpeedPid(char *cmd) {
  command.pid(&SpeedPid, cmd);
}
void CbYawPid(char *cmd) {
  command.pid(&YawPid, cmd);
}

void CbRollPid(char *cmd) {
  command.pid(&RollPid, cmd);
}

#elif AdjusParameter == ADJUST_BALL_PUSHING

void CbTouchXPid(char *cmd) {
  command.pid(&TouchXPid, cmd);
}

void CbTouchYPid(char *cmd) {
  command.pid(&TouchYPid, cmd);
}
#endif

//Wheel Motors and Drivers
double m1PrevEncoderAngleRad = 0;
float m1VelocityRadPerSec = 0;
float m1FilteredVelocityRadPerSec = 0;
LowPassFilter m1VelocityFilter = LowPassFilter(0.01);  // Tf = 10ms

double m2PrevEncoderAngleRad = 0;
float m2VelocityRadPerSec = 0;
float m2FilteredVelocityRadPerSec = 0;
LowPassFilter m2VelocityFilter = LowPassFilter(0.01);  // Tf = 10ms

double m1AngleRad = 0;
double m2AngleRad = 0;

float controlTimestepSec = 0;
unsigned long loopTimeUs = 0;
unsigned long previousControlTimeUs = 0;

BLDCMotor motor1 = BLDCMotor(7);  // Motor pole pairs
BLDCDriver3PWM driver = BLDCDriver3PWM(15, 7, 6, 16); // what are the numbers? replace with names

BLDCMotor motor2 = BLDCMotor(7);
BLDCDriver3PWM driver2 = BLDCDriver3PWM(40, 39, 38, 37);

MagneticSensorI2C sensor2 = MagneticSensorI2C(AS5600_I2C);
MagneticSensorI2C sensor1 = MagneticSensorI2C(AS5600_I2C);
TwoWire I2Cone = TwoWire(0);
TwoWire I2Ctwo = TwoWire(1);

void handleM1MotionCommand(char *cmd) {
  command.motion(&motor1, cmd);
}
void handleM1Command(char *cmd) {
  command.motor(&motor1, cmd);
}

void RXsbus();
void print_data(void);
void ImuUpdate(void);
void PIDcontroller_posture(float dt);
void RemoteControlFiltering(void);
void ReadVoltage(void);
void PidParameter(void);
void Robot_Tumble(void);
void DiagnosticLoop(void);
bool diagnosticImuReady = false;
unsigned long diagnosticLastRcFrameMs = 0;
bool diagnosticHasRcFrame = false;

void cpu0_task(void *ptParam) {
  while(1)
  {
    if(ten_msec_tick()){
      ble_loop();
    }
  }
}
bool ten_msec_tick(void) {
  static unsigned long lastMillis = 0;
  unsigned long currentMillis = millis();

  if (currentMillis - lastMillis >= 10) {
    lastMillis = currentMillis;
    return 1;
  }
  //Overflow handling
  if (lastMillis > currentMillis) {
    lastMillis = currentMillis;
  }
  return 0;
}

/**
 * @brief Initializes the robot's hardware and software components.
 *
 * This function runs once at startup. It configures serial communication,
 * initializes sensors (IMU, encoders), sets up motors and drivers with SimpleFOC,
 * configures PID controllers, initializes servos, reads calibration data from flash,
 * and sets up the command interface for serial debugging and tuning.
 */
void setup() {
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
void loop() {
#if SENSOR_DIAGNOSTIC_MODE
  DiagnosticLoop();
  return;
#endif
  loopTimeUs = micros();

  // iterative function setting the outter loop target

  if (Communication_object == COMMUNICATION_OBJECT_SIMPLEFOC_STUDIO) {
    if (Logging::profile() == Logging::Profile::Idle) motor1.monitor();
  } else if (Communication_object == COMMUNICATION_OBJECT_CONTROL_DUAL_MOTORS) {
    motor2.target = motor1.target;
  }

  motor1.move();
  motor2.move();

  // iterative setting FOC phase voltage
  motor1.loopFOC();
  motor2.loopFOC();


  m1AngleRad = -sensor1.getPreciseAngle();
  m2AngleRad = sensor2.getPreciseAngle();

  // user communication
  command.run();

  ImuUpdate();  // Update IMU data
  CtrlInput();  // BLE or remote control input
  RXsbus();

  ReadTouchDat();

  controlTimestepSec = (loopTimeUs - previousControlTimeUs) / 1000000.0f;
  if (controlTimestepSec >= 0.001f) {   //1kHz
    controlGateSequence++;
    TouchBiquadFilter();  // Touch screen filter

    RemoteControlFiltering();  // Remote control signal filtering
    ReadVoltage();             // Battery
    print_data();              // Serial port data printing

    Robot_Tumble();  // Machine fall detection
    statusLedTicks++;
    if (statusLedTicks >= statusLedPeriodTicks) {
      statusLedTicks = 0;
      if (statusLedOn == 1) {
        digitalWrite(BOARD_PIN_LED, LOW);  // On
        statusLedOn = 0;
      } else {
        digitalWrite(BOARD_PIN_LED, HIGH);  // Off
        statusLedOn = 1;
      }
    }

    if (Voltage <= 7.4)
      statusLedPeriodTicks = 20;
    else
      statusLedPeriodTicks = 100;

    if (imuSampleRateHz != prevImuSampleRateHz) {
      // Initialize second-order low-pass filter
      for (int axis = 0; axis < 6; axis++) {
        biquadFilterInitLPF(&ImuFilterLPF[axis], (unsigned int)imuLowPassCutoffHz, (unsigned int)imuSampleRateHz);
      }
      Logging::message(Logging::Level::Info, "RATE_HZ", "%.3f", imuSampleRateHz);
      prevImuSampleRateHz = imuSampleRateHz;
    }
    if (imuLowPassCutoffHz != prevImuLowPassCutoffHz) {
      // Initialize second-order low-pass filter
      for (int axis = 0; axis < 6; axis++) {
        biquadFilterInitLPF(&ImuFilterLPF[axis], (unsigned int)imuLowPassCutoffHz, (unsigned int)imuSampleRateHz);
      }
      Logging::message(Logging::Level::Info, "LPF_CUTOFF_FREQ", "%.3f", imuLowPassCutoffHz);
      prevImuLowPassCutoffHz = imuLowPassCutoffHz;
    }

    const CalibrationResult calibrationResult = calibration.update(
        static_cast<int>(CalibrationSelect),
        {attitude.roll, attitude.pitch},
        calibrationStore,
        {zeroBias.roll, zeroBias.pitch},
        {gyroBiasX, gyroBiasY, gyroBiasZ},
        {zeroBias.servo1, zeroBias.servo2, zeroBias.servo3, zeroBias.servo4},
        calibrateGyro);
    if (calibrationResult.clearRequest)
      CalibrationSelect = 0;

    if (calibrationResult.completion == CalibrationCompletion::Gyroscope) {
      Logging::message(Logging::Level::Info, "Calibration",
                       "gyroBiasX: %.2f, gyroBiasY: %.2f, gyroBiasZ: %.2f",
                       gyroBiasX, gyroBiasY, gyroBiasZ);
    } else if (calibrationResult.completion == CalibrationCompletion::Attitude) {
      Logging::message(Logging::Level::Info, "Calibration",
                       "Roll Zero Bias: %.2f, Pitch Zero Bias: %.2f",
                       zeroBias.roll, zeroBias.pitch);
    }

    if (calibrationResult.changedServos.servo1Changed)
      Logging::message(Logging::Level::Info, "Calibration", "zeroBias.servo1: %.2f", zeroBias.servo1);
    if (calibrationResult.changedServos.servo2Changed)
      Logging::message(Logging::Level::Info, "Calibration", "zeroBias.servo2: %.2f", zeroBias.servo2);
    if (calibrationResult.changedServos.servo3Changed)
      Logging::message(Logging::Level::Info, "Calibration", "zeroBias.servo3: %.2f", zeroBias.servo3);
    if (calibrationResult.changedServos.servo4Changed)
      Logging::message(Logging::Level::Info, "Calibration", "zeroBias.servo4: %.2f", zeroBias.servo4);

    const float wheelVelocityDt = DIAGNOSTIC_LIVE_TUNING_DEFAULTS ? controlTimestepSec : 0.01f;
    m1VelocityRadPerSec = (sensor1.getAngle() - m1PrevEncoderAngleRad) / wheelVelocityDt;
    m1FilteredVelocityRadPerSec = m1VelocityFilter(m1VelocityRadPerSec);
    m1PrevEncoderAngleRad = sensor1.getAngle();

    m2VelocityRadPerSec = -(sensor2.getAngle() - m2PrevEncoderAngleRad) / wheelVelocityDt;
    m2FilteredVelocityRadPerSec = m2VelocityFilter(m2VelocityRadPerSec);
    m2PrevEncoderAngleRad = sensor2.getAngle();

    float bodyH = BODY_HEIGHT_DEFAULT_M;
    float bodyRoll = BodyRollFiltered;

    if ((pid_gains_mode == REMOTE_CONTROL_PID_GAINS_MODE_OFF) || (RobotTumble == ROBOT_TUMBLING)) {
      balancePidNeedsPriming = true;
      if (Communication_object == COMMUNICATION_OBJECT_TWO_WHEEL_BALANCE) {
        motor1.target = 0;
        motor2.target = 0;
      }

      bodyH = BODY_HEIGHT_DEFAULT_M;
      BodyX = 0;
      bodyRoll = 0;
      BodyPitchingFiltered = 0;

      Angle_Pid.integral = 0;
      Speed_Pid.integral = 0;
      Yaw_Pid.integral = 0;
      wheelVelocityFeedbackCorrection = 0;
      driveEffectiveSpeed = 0;
      driveSpeedBodyXRaw = 0;

    } else if ((pid_gains_mode_is_enabled(pid_gains_mode)) && (RobotTumble == ROBOT_NOT_TUMBLING)) {
      PIDcontroller_posture(controlTimestepSec);  // PID controller

      if (roll_mode == REMOTE_CONTROL_ROLL_MODE_AUTO)
        bodyRoll = Roll_Pid.output;

      if (TargetBodyHeightOverrideM == BODY_HEIGHT_OVERRIDE_DISABLED_M)
        bodyH = BodyHeightCommandFilteredM;
      else
        bodyH = TargetBodyHeightOverrideM;
    }

    if (RobotTumble == ROBOT_TUMBLING)  // Machine fall
    {
      bodyH = BODY_HEIGHT_DEFAULT_M;
      BodyX = 0;
      bodyRoll = 0;
      BodyPitchingFiltered = 0;
    }

    const LegSolveResult rightLeg = LegKinematics::solveRight(
        {BarycenterX - BodyX, bodyH - bodyRoll, BodyPitchingFiltered});
    if (rightLeg.status != LegSolveStatus::Success)
      Logging::message(Logging::Level::Warning, "RightInverseKinematics", "no");

    const LegSolveResult leftLeg = LegKinematics::solveLeft(
        {BarycenterX - BodyX, bodyH + bodyRoll, BodyPitchingFiltered});
    if (leftLeg.status != LegSolveStatus::Success)
      Logging::message(Logging::Level::Warning, "LeftInverseKinematics", "no");

    if (posture_or_mark_mode == REMOTE_CONTROL_PM_POSTURE_MODE)  // Posture
    {

      // Set the angle of the four servos
      servoTraceAngle[0] = leftLeg.angles.joint1Degrees - zeroBias.servo1;
      servoTraceAngle[1] = leftLeg.angles.joint2Degrees - zeroBias.servo2;
      servoTraceAngle[2] = rightLeg.angles.joint1Degrees - zeroBias.servo3;
      servoTraceAngle[3] = rightLeg.angles.joint2Degrees - zeroBias.servo4;
      servoControl.setServosAngle(1, servoTraceAngle[0], -1, servoTraceAngle[1], -1, servoTraceAngle[2], 1, servoTraceAngle[3], 1);
    } else  // Assembly position and calibration
    {
      if ((int)CalibrationSelect == 3)  // Servo calibration
      {
        servoTraceAngle[0] = -zeroBias.servo1;
        servoTraceAngle[1] = -zeroBias.servo2;
        servoTraceAngle[2] = -zeroBias.servo3;
        servoTraceAngle[3] = -zeroBias.servo4;
      } else {
        servoTraceAngle[0] = servoTraceAngle[1] = servoTraceAngle[2] = servoTraceAngle[3] = 0;
      }
      servoControl.setServosAngle(1, servoTraceAngle[0], -1, servoTraceAngle[1], -1, servoTraceAngle[2], 1, servoTraceAngle[3], 1);
    }

    RobotLogCapture::observeServoAngles(servoTraceAngle);

    previousControlTimeUs = loopTimeUs;
  }
}

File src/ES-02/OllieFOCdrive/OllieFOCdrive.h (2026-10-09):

#ifndef OllieFOCdrive_h
#define OllieFOCdrive_h

#include <Arduino.h>
#include "filter.h"
#include "touchscreen.h"

#define ADJUSTMENT_PARAM_BALANCE_SPEED_YAW_ROLL 0
#define ADJUSTMENT_PARAM_BALL_PUSHING 1 // For tuning main balance and movement PID loops

#define COMMUNICATION_OBJECT_TWO_WHEEL_BALANCE 0 // Two-wheel balance mode
#define COMMUNICATION_OBJECT_SIMPLEFOC_STUDIO 1          // SimpleFOC Studio host computer
#define COMMUNICATION_OBJECT_CONTROL_DUAL_MOTORS 2       // Control dual motors

#define ROBOT_NOT_TUMBLING 0  // Robot is not tumbling
#define ROBOT_TUMBLING 1 // Robot is tumbling

#define REMOTE_CONTROL_PID_GAINS_MODE_OFF 0
#define REMOTE_CONTROL_PID_GAINS_MODE_ON_WITHOUT_TOUCH 1
#define REMOTE_CONTROL_PID_GAINS_MODE_ON_WITH_TOUCH 2

#define REMOTE_CONTROL_PM_POSTURE_MODE 0 // Posture control mode
#define REMOTE_CONTROL_PM_MARK_MODE 1    // Mark control mode

#define REMOTE_CONTROL_ROLL_MODE_MANUAL 0
#define REMOTE_CONTROL_ROLL_MODE_AUTO 1

#define REMOTE_CONTROL_ATTITUDE_MODE_DEFAULT 0
#define REMOTE_CONTROL_ATTITUDE_MODE_PITCHING_ADJUST 1 // Pitching adjustment mode
#define REMOTE_CONTROL_ATTITUDE_MODE_BALL_POISE 2      // Ball poise mode

typedef union 
{
  struct 
  {
    float x;
    float y;
    float z;
  };
  float axis[3];
} Axis3f;

//Attitude data structure
typedef struct  
{
  Axis3f accf;       //Filtered acceleration (G)
  Axis3f gyrof;      //Filtered gyroscope (deg/s)  
  Axis3f acc;       //Acceleration (G)
  Axis3f gyro;      //Gyroscope (deg/s)  
  float roll;
  float pitch;
  float yaw;
  float temp;
} attitude_t;


typedef struct  
{
  Axis3f acc;       //Acceleration (G)
  Axis3f gyro;      //Gyroscope (deg/s) 
  float roll;
  float pitch;
  float yaw;

  float servo1;
  float servo2;
  float servo3;
  float servo4;

  
} zeroBias_t;

class MyPIDController {
  private:


  public:
  
    float Kp;  // Proportional coefficient
    float Ki;  // Integral coefficient
    float Kd;  // Derivative coefficient
    float deriv;
    float integral;  // Error integral
    float previousError;  // Previous error
    float iLimit;
    float outputLimit;
    float outP;
    float outI;
    float outD;    
    float output;
    float error;
    float enableDFilter;
    biquadFilter_t dFilter;  //
    float cutoffFreq;
  
    // Constructor, initialize PID parameters
    MyPIDController(float p, float i, float d, float iLimit, float outputLimit,float dt, float EnableDFilter, float CutoffFreq) {
      Kp = p;
      Ki = i;
      Kd = d;
      enableDFilter = EnableDFilter;
      integral = iLimit;
      previousError = outputLimit;//Output limit
      cutoffFreq = CutoffFreq;
      
      if ((int)enableDFilter==1)
      {
        biquadFilterInitLPF(&dFilter, (unsigned int)cutoffFreq, (unsigned int)(1.0f / dt));
      }      
      
    }

    // Function to calculate PID output, parameters include error and time interval dt
    float compute(float Error, float dt) {

      error = Error;
      // Calculate error integral
      integral += error * dt;

      //Integral limit
      if (iLimit != 0)
      {
        if(integral>iLimit)
          integral = iLimit;
        if(integral<(-iLimit))
          integral = -iLimit;
        
      }

      // Calculate error derivative
      deriv = (error - previousError) / dt;
      if (enableDFilter==1)
      {
        deriv = biquadFilterApply(&dFilter, deriv);
      }

      
      outP = Kp * error;
      outI = Ki * integral;
      outD = Kd * deriv;


      // Calculate PID output
      output = outP + outI + outD;

      // Update previous error
      previousError = error;

      //Output limit
      if (outputLimit != 0)
      {
        output = constrain(output, -outputLimit, outputLimit);
      }
  

      return output;
    }

    // Function to set PID coefficients
    void setPID(float p, float i, float d, float iLimit, float outputLimit,float dt, float EnableDFilter, float CutoffFreq) {
      Kp = p;
      Ki = i;
      Kd = d;
      enableDFilter = EnableDFilter;
      integral = iLimit;
      previousError = outputLimit;//Output limit
      cutoffFreq = CutoffFreq;
      
      if ((int)enableDFilter)
      {
        biquadFilterInitLPF(&dFilter, (unsigned int)cutoffFreq, (unsigned int)(1.0f / dt));
      }    
    }
};




#endif

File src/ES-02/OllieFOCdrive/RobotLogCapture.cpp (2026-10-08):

#include "RobotLogCapture.h"

#include "Logging.h"

#include <limits.h>

namespace {
constexpr uint32_t kSelectedDebugIntervalMs = 50;

uint32_t lastSbusPrintMs = 0;
uint32_t lastChannelTraceMs = 0;

int32_t servoMinimum[4] = {0, 0, 0, 0};
int32_t servoMaximum[4] = {0, 0, 0, 0};
int32_t servoLatest[4] = {0, 0, 0, 0};
bool servoWindowStarted = false;

bool isChannelSelector(int selector) {
  return selector >= 60 && selector <= 75;
}

bool gateDue(uint32_t nowMs, uint32_t &lastMs) {
  if (static_cast<uint32_t>(nowMs - lastMs) < kSelectedDebugIntervalMs) return false;

  lastMs = nowMs;
  return true;
}
}

namespace RobotLogCapture {

Logging::Profile profileForSelector(int selector) {
  if ((selector >= 1 && selector <= 45) || isChannelSelector(selector))
    return Logging::Profile::SelectedDebug;

  switch (selector) {
    case 55: return Logging::Profile::Trace;
    case 56: return Logging::Profile::Control;
    case 57: return Logging::Profile::Balance;
    case 58: return Logging::Profile::Drive;
    default: return Logging::Profile::Idle;
  }
}

bool isMeasurementProfile(Logging::Profile profile) {
  switch (profile) {
    case Logging::Profile::Diagnostic:
    case Logging::Profile::Trace:
    case Logging::Profile::Control:
    case Logging::Profile::Balance:
    case Logging::Profile::Drive:
      return true;
    case Logging::Profile::Idle:
    case Logging::Profile::SelectedDebug:
      return false;
  }
  return false;
}

void setProfileForSelector(int selector) {
  Logging::setProfile(profileForSelector(selector));
}

bool selectedDebugDue(Logging::DebugSelector selector, uint32_t nowMs) {
  const int value = static_cast<int>(selector);
  if (value < 1 || (value > 45 && !isChannelSelector(value))) return false;

  if (value == 8) return gateDue(nowMs, lastSbusPrintMs);
  if (isChannelSelector(value))
    return gateDue(nowMs, lastChannelTraceMs);
  return true;
}

void resetControlWindow() {
  for (int i = 0; i < 4; ++i) {
    servoMinimum[i] = 0;
    servoMaximum[i] = 0;
    servoLatest[i] = 0;
  }
  servoWindowStarted = false;
}

void observeServoAngles(const int angles[4]) {
  if (angles == nullptr) return;

  if (!servoWindowStarted) {
    for (int i = 0; i < 4; ++i) {
      servoMinimum[i] = angles[i];
      servoMaximum[i] = angles[i];
      servoLatest[i] = angles[i];
    }
    servoWindowStarted = true;
    return;
  }

  for (int i = 0; i < 4; ++i) {
    if (angles[i] < servoMinimum[i]) servoMinimum[i] = angles[i];
    if (angles[i] > servoMaximum[i]) servoMaximum[i] = angles[i];
    servoLatest[i] = angles[i];
  }
}

void copyServoRangesAndBeginNextWindow(int32_t ranges[4]) {
  if (ranges == nullptr) return;

  for (int i = 0; i < 4; ++i) {
    if (!servoWindowStarted) {
      ranges[i] = 0;
      continue;
    }

    const int64_t span = static_cast<int64_t>(servoMaximum[i]) - servoMinimum[i];
    ranges[i] = span > INT32_MAX ? INT32_MAX : static_cast<int32_t>(span);
    servoMinimum[i] = servoLatest[i];
    servoMaximum[i] = servoLatest[i];
  }
}

}

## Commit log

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2026-10-04 feat(ros2): add HMMD range-Doppler sensor and heatmap
    Add fixed raw matrix messages, bounded serial parsing and recovery, diagnostics, a raw/log heatmap, and stationarity recording/replay documentation. Local verification passes 15 tests; the ROS graph test is skipped because this host has no ROS runtime. CM5 build, rosbag2 integration and live sensor validation remain outstanding.
    [protocol.py, sensor_node.py, serial_session.py]
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2026-10-07 fix: preserve diagnostic IMU rate precision
    [OllieFOCdrive.ino]
2026-10-07 Fix biquad filter sampling rate units
    [OllieFOCdrive.h, OllieFOCdrive.ino, touchscreen.cpp]
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2026-10-07 fix(logging): bound debug output and clarify diagnostic mode
    Record the follow-up to clean up logging commands.
    [test_serial_logger.py]
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2026-10-08 feat(logging): integrate project-local logging module (#4)
    * refactor(logging): freeze typed module interface
    * refactor(logging): expose formatter health status
    * refactor(logging): cover semantic debug payloads
    * feat(logging): add robot log capture policy
    * fix(logging): route application diagnostics through logger
    * feat(logging): integrate project-local logging module
    * refactor(logging): clarify servo range window capture
    [ICM42688.cpp, LogFormat.cpp, OllieFOCdrive.ino]
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2026-10-09 fix: updated TorqueControlType for only one motor after SimpleFoc upgrade
    [OllieFOCdrive.ino]
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2026-10-12 fix(pid): store iLimit/outputLimit and start PID state at zero
    The constructor and setPID() wrote their iLimit and outputLimit arguments
    into integral and previousError, leaving the real members unset and the
    state wrong. Store the limits, zero integral, previousError and outputs,
    and compare enableDFilter the same way in constructor, setPID and
    compute(). Add a host test with a minimal Arduino.h stub.
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2026-10-12 test(log): pin the K46 gyro FFT line in the format fixture
    K46 was formatted but absent from the fixture. The fixture now covers
    K1..K46 and K60..K75 against the unchanged formatter.
2026-10-12 fix(sketch): parse SBUS once per loop and zero drive commands on RC loss
    BLE wins while connected and RXsbus runs only otherwise. When SBUS is the
    active source and no frame arrived for 100 ms or the receiver reports a
    failsafe, MovementSpeed and BodyTurn are forced to zero while the mode
    switches and body commands keep their last values.
2026-10-12 fix(log): print tY for the K40 second touch coordinate
    With touch state 0, K40 printed tX twice. The fixture now pins tY, matching K26.
2026-10-12 fix(sketch): log gyroscope data for K46 and acceleration in diagnostic rows
    K46 emitted accelerometer values under a gyro FFT header, and the diagnostic
    CSV filled its acceleration columns from filtered angular velocity. Collapse
    the identical K40 branches.
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2026-10-12 refactor(log): return the formatted length from appendf
    formatDebug repeated the length ternary in 49 cases. appendf now returns the
    new length or -1, so each case returns it directly. Selector ranges move into
    LogSamples.h as isSelectedDebugSelector and isChannelDebugSelector. Formatted
    output is unchanged; a before/after capture over all selectors differs only in
    the K40 line fixed in the previous commit.
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2026-10-12 fix(sketch): guard gyro calibration, hold unreachable legs, rate-limit warnings
    Refuse the blocking gyro calibration while the balance loop is active, keep
    the previous servo angles of a leg whose pose is unreachable, and emit the
    low-battery and inverse-kinematics warnings at most once per second. Use
    fabsf for the float tumble check.
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2026-10-12 test(log): treat K46 as a selected debug selector
    K46 joined the selected debug range with the gyro FFT channel. The capture
    test still expected it to be idle and failed at HEAD.
2026-10-12 refactor(ble): remove dead BLE and RobotProtocol code, fix log typos
    Delete ble_test, test_rx_json, tick declarations, ble_offline_processing,
    ble_send_string, ble_tx_add_json, undefined declarations, commented-out
    blocks, unused enum values and RobotProtocol members and methods.
    get_device_info now reports the rounded battery voltage and level.
2026-10-12 fix(imu): int32 gyro calibration sums and saturating bias correction
    Gyro calibration summed 1000 samples in int16_t, which wrapped once the
    mean offset exceeded about 32 counts. Bias correction truncated the float
    bias and could wrap at full scale; it now rounds once and saturates.
    Begin() shares the filter init path with setSettings(), the count scales
    are named once, and calibration status goes through Logging::message with
    one report per motion streak.
2026-10-12 docs(control): align control-flow and hardware overview with current names
    control-flow.md describes the current BLE/S.BUS read order, which no longer
    calls the S.BUS reader twice per loop, and uses the renamed functions. The
    hardware overviews name the renamed battery reader.
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2026-10-12 fix(sbus): copy full channel and servo default arrays in begin()
    memcpy copied 18 bytes into 18 x int16_t arrays, so only the first nine
    channel defaults were initialised. Use sizeof for both copies.
2026-10-12 refactor(sketch): remove unused globals and stale comments
    Drop BarycenterX, SlideStep, TouchXPidOutputFiltered and the wheel angle
    globals, translate or delete the remaining non-English and empty comments,
    and replace question TODOs with factual comments.
2026-10-12 refactor(sketch): replace print_data with DebugTelemetry
    The sketch collects a TelemetryInputs snapshot each control tick and hands it
    to DebugTelemetry::submit. The battery minimum and trace sequence live in a
    TelemetryState owned by the sketch; ReadVoltage updates the minimum there.
2026-10-12 refactor(sketch): share pi constants via MathConstants.h
    Replace the per-file pi definitions (imu.cpp, MahonyFilter.cpp, filter.h
    M_PIf macro, LegKinematics.cpp KINEMATICS_PI) with one header. The
    LegKinematics constant stays double so its baseline test is unchanged.
2026-10-12 fix(ble): bound TX string copy, hand RX frames over under a spinlock, drop LED2 toggles
    ble_tx_add_string no longer copies through a fixed stack buffer, the last
    TX frame is zero-padded within the buffer, onWrite stores the frame in a
    single slot guarded by a portMUX that ble_rx_processing takes into private
    state, and the BLE task no longer toggles the status LED on GPIO 35.
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2026-10-12 refactor(sbus): remove dead API and leaked macros
    Delete the unused passthrough, servo output and bit-counter code, the
    commented-out bitwise decoder, and the public servos[]/sbusData/
    failsafe_status/passthrough members. Move the port, pins and baud out
    of the header into the .cpp and use Serial2 directly. Always decode all
    16 channels (ALL_CHANNELS was always defined). Signal states are
    file-private because the sketch only calls Failsafe().
    Channel decoding and FeedLine resync are unchanged; a randomized host
    comparison against the previous build produced identical channels,
    failsafe status and toChannels.
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2026-10-12 refactor(log): remove the unused status, level and capture helpers
    Logging::status and its counters, Logging::setLevel, RobotLogCapture::
    resetControlWindow and RobotLogCapture::isMeasurementProfile had no callers
    outside the logger and its host tests. Counters that only fed status()
    (queued, rejected, filtered, suppressed, format failures, truncation, queue
    depth, and the unread suppressed-record count) are removed. Dropped and write
    failures stay because the CSV rows report them. The host tests assert the
    same latches through submit() and message() results.
2026-10-12 fix(ble): serialise ble_tx_q and ble_ctrler writers, make ble_connected volatile
    ble_tx_q is pushed from the main loop and cpu0_task and drained by cpu0_task;
    every queue operation now runs under one spinlock. The producer no longer reads
    a queued entry after the push, and a failed push frees its allocation.
    ble_ctrler writes (frame copy, disconnect clear) are locked copies.
2026-10-12 fix(calibration): skip NVS session when no servo trim changed
    Calibration::update() no longer calls saveChangedServos on unchanged
    ticks, and the store returns before touching Preferences for an empty
    mask. Value-initialise lastSeenServos_.
2026-10-12 fix(kin): finite leg angles and one shared solver
    Determine reach status before any acos, clamp acos/asin ratios, and
    substitute a safe pose for non-finite input so angles are always finite.
    Merge solveLeft and solveRight into one solver (the left mirror cancels
    exactly), name the clamp limits and the single pi constant.
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2026-10-12 fix(pid): apply limits and start PID state at zero (#5)
    * fix(pid): store iLimit/outputLimit and start PID state at zero
    * refactor(pid): delete unused MyPIDController::setPID
    ---------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
2026-10-15 feat(lidar): add live scan viewer and automatic startup (#19)
    * feat(lidar): add LDS08RR browser and ROS integration
    * docs(lidar): record voltage readings and protocol cleanup
    * docs(lidar): record reported 3 V TX peak
    * feat(lidar): add responsive scan UI and boot startup
    * feat(lidar): add direction labels and 30-degree grid
    * fix(hmmd): reserve UART0 for LiDAR and use UART2
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2026-10-19 feat(link): send wheel odometry and IMU at 50 Hz
    link_frame encodes a Message with nanopb and frames it as COBS(payload ||
    CRC-16/CCITT-FALSE) 0x00. link_uart publishes WheelOdometry and Imu on UART1
    without blocking; a frame that does not fit the TX buffer is dropped and
    counted. loop() calls it on every 20th 1 kHz gate tick.
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2026-10-19 feat(ros2_pc): add navbot_link_bridge rclpy node
    Polls the serial port at 200 Hz and publishes nav_msgs/Odometry on odom,
    the odom->base_link TF (optional) and sensor_msgs/Imu on imu/data. Reopens
    the port every second after an error.
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2026-10-20 refactor(layout): move docs, notes, CAD and tests into the closed layout
    docs/<system>/ is flat: hardware/, software/, plans/, assets/.
    Observations and captures move to lab/<system>/, design sources to
    cad/<system>/, the systemd unit to src/ros2_pc/systemd/, and script
    tests plus their fixtures to tests/<area>/. Captures cited by notes are
    tracked under lab/robot/captures/. Links and repo paths are rewritten.
2026-10-20 docs(layout): placement rules in AGENTS.md, system indexes, merged agent notes
    AGENTS.md gets the closed "Where files go" table and rules. docs/robot and
    docs/ros2_pc get index pages. The HMMD agent README and vendor README merge
    into docs/ros2_pc/hardware/hmmd-radar.md. README procedures move to
    docs/robot/software/trace-capture.md; the stale software tree and IMU name
    are fixed. Lab notes get a Status line.
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2026-10-20 fix(layout): keep vendor demo bytes and drop an uncited capture
    The move rewrote hmmd-raspberry-demo.py.txt with LF line endings; restore
    the original CRLF file. drive-yp4-diagnose-01.md is a generated report no
    note cites, so it leaves lab/ (kept locally in work/).
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2026-10-21 docs(robot): restructure hardware docs in English and record servo 3/4 GPIO swap
    Rewrite the hardware overview, electronics reference and netlist headers in
    English, merge wireless-logging-constraints into the reference, note that
    UART1 now carries the ros2_pc link, and document the servo 3/4 swap between
    PCB nets and firmware. Drop the roadmap item on native USB CDC, which the
    hardware cannot support.
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2026-10-22 docs(robot): plan torque-mode balance control with fixed legs and trim
    Propose one control chain for standing and driving with the PC and
    LiDAR payload: fixed zero-angle leg pose, slow speed loop to a bounded
    tilt reference, tilt P and gyro damping commanding wheel current in
    SimpleFOC torque mode, balance-first current allocation, and a CH9
    payload trim. Includes the available-current limits of the configured
    motors, staged commissioning, and an implementation checklist. Removes
    Bluetooth and the touchscreen from the planned firmware.
2026-10-22 docs(robot): decide fault action and remove motor test modes in plan
    Faults and disable coast the wheels: 0 A, then both drivers disabled,
    servos keep the fixed pose, rearm only by an enable-switch edge. Stage 3
    verifies it. The SimpleFOC Studio and dual-motor modes, the motor-1
    monitor, and Commander T and M are removed; the bounded current-test
    and motor identification commands replace them.
2026-10-22 docs(robot): document RC value chain and plan its cleanup
    Record the measured transmitter-to-SBUS values (1000/1500/2000 us to
    192/992/1792, CH3 forward high, CH4 left low) in a lab note, and
    describe the conversion chain to controller values in the RC channel
    map. Add roadmap items to replace the chain with one physical-unit
    mapping per channel and to make the sensor diagnostic mode accept
    serial commands and report channel values.
2026-10-22 docs(robot): record RC switch positions and close the channel map
    CH5 has three positions, CH6 and CH7 are latching two-position
    switches. The plan now decodes them with fixed raw bands, keeps balance
    enabled in CH5 positions 1 and 2, saves trim on the CH6 0-to-1 edge,
    and selects commissioning with CH7. No open decisions remain.
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2026-10-22 fix(robot): buffer UART TX so trace output does not stall the control loop
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2026-10-22 docs(robot): record loop rate after the TX buffer fix and explain the IMU counters
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2026-10-22 fix(robot): time wheel speeds from the encoder read and report them forward positive
    updateWheelVelocities() divided by 0.01 s unless live tuning was on, and negated
    only motor 2. It now uses the measured read interval and the WheelBoundary signs.
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2026-10-22 feat(robot): raise the T current cap to 0.35 A (2.0 V at 5.75 ohm)
    Operator-authorized on 2026-10-22; the old 0.02 A cap was sized for the 22 ohm
    estimate and no longer moved the wheels.
2026-10-22 fix(robot): measure wheel speed from shaftAngle() so both wheels share the voltage.q sign
    Motor 2's sensor runs opposite to its shaft_velocity (sensor_direction CW), so raw
    sensor angles gave the right wheel the wrong sign. Found on the bench with T 0.35.
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2026-10-22 refactor(robot): remove touch_x from the DRIVE trace row
    Drop touchXFiltered from Logging::DriveSample, its formatter, and the
    DRIVE header in capture_balance_trace.py, the trace-capture doc, and the
    schema test. Later DRIVE columns move one place left; the serial logger
    distinct-value row and its sentinel are renumbered to match. The
    telemetry golden stream and fixtures are regenerated for the new layout.
2026-10-22 refactor(robot): remove touch state telemetry
    Drop the TouchStatus snapshot, the touch field of the telemetry inputs,
    and the selectors that only printed it (26, 27, 36, 40). The touch
    point and touch-state payloads, their formatters, and the selector 26/40
    validity check in Logging::submit go with them. The retired numbers stay
    unused.
    The serial logger fixture and the dispatch test lose the touch-state
    variant. The golden telemetry stream is regenerated because the test
    filler draws fewer values.
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2026-10-22 docs(robot): remove touchscreen and HMI mentions
    Drop the touch input from the control flow, RC channel map, tuned defaults,
    electronics and system overview, the README HMI row, and the Touch X/Y PID row
    of the Package 3 table. The stand mounting-hole page stays, because the lidar
    stand CAD still uses its hole pattern; its heading no longer names the touchscreen.
2026-10-22 refactor(robot): remove the roll PID and roll leveling
    Remove rollPid, rollPidSettings, rollMode (CH7 is now unused), Commander R,
    the roll telemetry selectors K31 and K32, and the top-ball Y filter that only
    fed roll leveling. The yaw loop keeps its integral off unconditionally, which
    matches the default manual-roll behaviour. Update the telemetry golden stream,
    the serial-logger fixture, and the RC channel map.
2026-10-22 refactor(robot): remove the speed PI to bodyX
    Remove speedPid, Commander S, driveSpeedBodyXRaw, kDriveBodyXLimitM,
    bodyPitchingCorrect, and bodyX. The leg IK takes x = 0 until the fixed pose
    replaces it. The tilt-based speed reduction only shaped the speed setpoint, so
    it goes with the loop; its gain and command are removed in the next row.
    Telemetry: drop the DRIVE speed and body_x columns, the BAL body_x column, the
    K9 speed gains, and selectors K23, K41 and K42. Update the golden stream, the
    serial-logger fixtures, the drive fixture and schema test, and the docs.
2026-10-22 refactor(robot): remove the braking-only wheel correction
    Remove wheelSpeedFeedbackGain, wheelVelocityFeedbackCorrection,
    kDriveWheelFeedbackLimit, Commander V, and the average wheel velocity that
    only the braking term used. Remove the DRIVE wheel_speed_feedback column and
    the matching selectors and log fields. Update the golden stream, the
    serial-logger and drive fixtures, the schema test, the capture whitelist, and
    the trace-capture doc.
2026-10-22 refactor(robot): remove the control torque compensation
    Remove controlTorqueCompensation and its setter. The setter was never
    registered as a Commander command, so no serial command reached it. The
    torque offset is applied only to the wheel targets that balance no longer
    produces.
2026-10-22 refactor(robot): remove the balance angle PID
    Remove anglePid, anglePidSettings, balancePidNeedsPriming, and Commander P.
    The yaw loop keeps its output for now, but both wheel targets stay at 0 A.
    Remove the angle telemetry: the K9 angle gains, selector K22, the K45 angle
    error, and the CTRL, BAL, and DRIVE angle columns. Update the golden stream,
    the serial-logger and drive fixtures, the schema and analysis tests, the
    command whitelist, and the docs. The analysis report drops its Winkel-I
    column, which came from the angle integral.
2026-10-22 refactor(robot): remove the gain presets and live-tuning define
    Remove PidPreset, BalancePidPreset, kBalancePid, kYawPid, applyPidPreset(),
    applyBalancePidPreset(), applyPidParameters(), and pidParameterTuning. The yaw
    gain now starts from literal values. Remove DIAGNOSTIC_LIVE_TUNING_DEFAULTS
    with its last users: the CH3 x2 scaling in readSbus() and the presets. Remove
    selector K44 and its TuningState payload. Remove the dated tuned-defaults page,
    which described only the removed presets, and its index link. Update the
    golden stream, the serial-logger fixtures, the whitelist, and the docs.
2026-10-22 refactor(robot): remove the height, pitch, roll, and ball commands
    Remove the body height, pitch, and roll commands and their filters, the top
    ball X and Y inputs, the posture, mark, and attitude mode switches, the
    Commander O (target height), F (filter cutoff), and J (filter enable) entries,
    and the remote-control filter with its initialiser. The leg solver now takes a
    constant standing pose, and writeServos() keeps only calibration and the
    solved posture. Remove telemetry selectors K20, K21, K24, K25, K28, and K37,
    the TRACE ch6_mode column, and the DRIVE body_pitching_f, top_ball_x, and
    body_pitching columns. Drop the CH6, CH8, CH9, and CH10 labels from the
    remote-status tool. Update the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
2026-10-22 refactor(robot): remove the posture controller, IK, and LegKinematics
    Remove runPostureController() and computeBodyPose(). Each tick now holds both
    wheel targets at 0 A, unless the motor diagnostic owns them, and writes the
    fixed standing pose: each servo at -trim through writeLegServos(). Servo
    calibration (E 3) writes the same pose, so it works with balance disabled.
    Delete LegKinematics and tests/kinematics, since nothing calls them now. The
    yaw settings and telemetry stay: no code updates the yaw output, and package 4
    replaces that loop. Update the control-flow page for the controller and code
    map changes, and mark package 3 done in the plan.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
2026-10-22 docs(robot): state the current CH9 and T/M roles in the plan
    CH9 no longer drives ball X, and Commander T and M are the bounded
    diagnostics that implement the current-test command.
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2026-10-22 feat(robot): compute per-wheel current envelopes in BalanceController
    The allocator needs to know what current each wheel can actually
    deliver at its present speed and bus voltage. Vmax is limited by the
    voltage limit and the sagged, modulation-scaled bus; back-EMF uses
    SimpleFOC's formula; the wheel sign puts both intervals in forward-
    positive body terms. An invalid model (non-finite, inverted, bus out of
    range, missing R/KV/sign) latches a fault, including on the arming tick
    so drivers are never enabled on it. A NaN wheel speed now faults as an
    invalid envelope on the first tick instead of as overspeed after the
    debounce; both fail closed.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
2026-10-22 feat(robot): shape speed and yaw demand in BalanceController
    The driver's request must not reach the balance loop raw. Speed is
    slewed at an acceleration cap and braked faster toward zero, yaw is
    clamped, and both caps scale with demandScale (acceleration and yaw
    first, as the plan's reserve rule asks; the brake ramp does not scale).
    A stale or invalid motion source counts as a zero request and ramps
    down at the brake cap, with age checked by unsigned subtraction. Caps
    that would hold or reverse speed (zero brake cap, negative rate, NaN)
    latch an InvalidConfig fault rather than failing silently. All caps
    are uncommissioned Config fields.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
2026-10-22 feat(robot): add speed loop and tilt reference to BalanceController
    Speed is controlled by leaning the chassis: a 50 Hz-decimated PI turns
    the speed error into a tilt-reference correction on top of the trim,
    clamped to the tilt range and slew-limited before the balance law (step
    6) sees it. The speed integral is the only integrator and follows the
    plan's antiwindup precedence: frozen while downstream effort is
    limited, and while the tilt reference is clipped it only accepts steps
    back toward the feasible band. A stored trim larger than the tilt
    limit is rejected as InvalidConfig rather than silently clamped. All
    gains and limits are uncommissioned Config fields.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
2026-10-22 feat(robot): add balance and yaw control with effort allocation
    The controller now turns the tilt error and rate into a common wheel
    current and the yaw-rate error into a differential, then allocates both
    inside the per-wheel envelopes using the plan's formulas (balance
    first: yaw yields when the envelope leaves no room). The allocation is
    redone every tick from the held demands, so a held current can never
    exceed the envelope of the present wheel speed. Reserve scales the next
    tick's demand linearly and also feeds the speed-integral freeze; a
    common effort clipped for longer than the authority duration latches
    AuthorityExhausted. Only yawP is used; there is no yaw integral. All
    gains and th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
2026-10-22 feat(robot): scale demand in the plan's order and tighten save preconditions
    The plan reduces requested acceleration and yaw first and the cruise
    cap only after that; shapeDemand scaled all three together. Acceleration
    and yaw now fall to zero at demandScaleCapStart and the cruise cap falls
    below it. The save and transfer checks also used the arming bands for
    the near-zero request test; they get their own tolerances, and voltage
    or current clipping now blocks both, since the plan allows neither
    effort nor tilt clipping at standstill.
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
